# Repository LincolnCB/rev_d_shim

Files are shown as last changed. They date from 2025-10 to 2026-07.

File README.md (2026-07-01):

# Shim Amplifier System, Rev. D



This repo is the source code for the Rev. D version of our shim amplifier system. It is primarily written by me, Lincoln Craven-Brightman, and based on the work of Pavel Demin, who provided a great starting point with his repo for Zynq-7000 development.

To use this repo, you will need the following repos. Each repo has a DOI that can be accessed on its own README.
- Our build environment repo, [Zynq Toolbox](https://github.com/LincolnCB/zynq_toolbox) ([https://github.com/LincolnCB/zynq_toolbox](https://github.com/LincolnCB/zynq_toolbox)), which is an extension of Pavel's original [Red Pitay Notes](https://github.com/pavel-demin/red-pitaya-notes) repo.
- The hardware design files for the Rev. D version of our shim amplifier system, which have been created by Don Straney and are available in our [hardware repo](https://github.com/stockmann-lab/shim_amp_hardware_linear/) ([https://github.com/stockmann-lab/shim_amp_hardware_linear/](https://github.com/stockmann-lab/shim_amp_hardware_linear/))

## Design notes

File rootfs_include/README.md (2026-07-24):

# Rev D Shim Amplifier

This system includes multiple command-line tools for controlling, driving, and diagnosing the shim hardware. These all currently need to be run with sudo privileges in order to handle memory mapping.

| Tool | Type | What it does |
|---|---|---|
| `reset-shims` | One-shot utility | Safely resets the shim hardware to a known idle state — powers off and pulses the command/data buffer resets. Good for recovering between runs without a power cycle. |
| `status` | One-shot, read-only | Reads the FPGA system status register and prints a human-readable snapshot (hardware state, trigger count, clock frequencies, timing debug, per-board FIFO status). Observes only, never drives hardware. |
| `static-shims` | Interactive | Drives the shims with **static (DC)** currents. Set per-channel currents manually, from files, or on triggers. |
| `waveform` | One-shot, file-driven | Plays a multi-channel **waveform** from a CSV on the DACs, optionally reads back ADC samples, and logs trigger times. Configurable clock, lockout, and iteration count. |
| `shim-test` | Interactive | Manual test bench for **every aspect** of the shim driver — exercise the system, clock, DACs, ADCs, trigger, and streaming/experiment features by hand. For bring-up, debugging, and validation. |

## At a glance

- **Diagnostics / recovery:** `status` (inspect the hardware) and `reset-shims` (recover to idle).
- **Driving the hardware:** `static-shims` for DC currents and `waveform` for time-varying playback.
- **Development / debugging:** `shim-test` as the low-level interactive driver test tool.

Use the `-h` or `--help` option with any command to see its usage and available options.

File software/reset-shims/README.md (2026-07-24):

# reset-shims

Small utility that safely resets the Rev D Shim hardware to a known idle state.

On run it:
1. Maps the system control register (`0x40000000`) via `/dev/mem`.
2. Powers the system off (control and power boards disabled).
3. Pulses the 17-bit command and data buffer resets (assert, brief delay, release).

Useful for recovering the buffers/state between runs without a full power cycle.

## Usage

```bash
reset-shims
```

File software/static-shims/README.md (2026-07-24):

# static-shims

Interactive command-line tool for driving the Rev D shim amplifier with **static** (DC) currents. It boots the FPGA hardware, then accepts single-character commands to set per-channel currents manually, from files, or on external/forced triggers.

## Usage

```bash
static-shims [--verbose] <channel_count>
```

- `channel_count` — number of active shim channels (1–64).
- `--verbose` — enable detailed logging.

On start it initializes hardware, configures the clock, and drops into a `static-shims>` prompt. `Ctrl+C` (or `Q`) powers the system off safely before exiting.

## Commands

**General**
| Cmd | Action |
|---|---|
| `H` | Brief help |
| `?` | Extended guide (file format + commands) |
| `Q` | Quit (powers off) |
| `S` | Print system/hardware status |
| `P` | Power amplifier on |
| `X` | Hard reset: power off, unload file, clear buffers |
| `Z` | Zero all currents, unload file, clear buffers |
| `I [file]` | Read currents from ADC (optionally dump to file) |

**Manual**
| Cmd | Action |
|---|---|
| `n x` | Set channel `n` to `x` amperes |
| `U x1 x2...` | Update all channels to given amps |
| `B x1 x2...` | Buffer all channels, wait for trigger |
| `C` | Run calibration |
| `D t` | Set trigger lockout time (ms, default 10.0) |
| `T [n]` | Trigger next shim row `n` times (default 1) |

**File**
| Cmd | Action |
|---|---|
| `L [file]` | Load shim block file (or reload last) |
| `A [data]` | Load inline array as a shim block (`/` = newline) |
| `E` | Exit loaded file, reset trigger counter |
| `R` | Reset buffers, restart loaded file |

## Layout

- `static-shims.c` — entry point / REPL loop and boot sequence.
- `src/`, `include/` — `commands/` (command parsing + execution), `input/` (line parsing), `file_handling/` (shim block files), and `static_hardware/` (`hw_*` hardware control API, wrapping the FPGA `sys`/`clk`/`dac`/`adc`/`trigger` controllers).

Max 64 channels; currents limited to ±5.0 A.

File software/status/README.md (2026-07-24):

# status

Command-line diagnostic tool that reads the Rev D shim amplifier's FPGA system status register (mapped at `0x40100000`) and prints a human-readable snapshot of the hardware state. It is read-only — it only observes and reports, and never drives or reconfigures the hardware.

## Usage

```bash
status
```

No arguments. Run it on the target to dump the current status of the shim hardware.

## What it reports

- **Hardware status** — decoded state (`S_IDLE`…`S_HALTED`), status code (`STS_*`), and the board number associated with the current status.
- **Trigger count** — number of hardware triggers seen.
- **Clock frequencies** — SPI clock and SPI source clock, in Hz.
- **Timing debug register** — clock-locked/SPI-off flags, DAC/ADC `~CS` high times, and the SPI clock snoop reconfiguration state machine state.
- **Minimum delay times** — DAC and ADC "delay too short" thresholds, in SPI clock cycles.
- **Per-board FIFO status (boards 0–7)** — DAC and ADC command/data FIFO status (word count, full / almost-full / empty / almost-empty / present flags), the last received command word, and the command count since reset.
- **Trigger FIFOs** — command and data FIFO status.

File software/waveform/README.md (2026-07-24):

# waveform

Command-line tool that plays a multi-channel waveform on the Rev D shim amplifier's DACs, optionally reads back ADC samples, and logs hardware trigger times. It streams commands to the FPGA over the DAC/ADC/trigger control interfaces and powers the hardware safely on and off around the run.

## Usage

```
waveform <file.csv> [OPTIONS]
```

| Argument / flag | Type | Default | Meaning |
|---|---|---|---|
| `<file.csv>` | path | — (required) | DAC waveform input file |
| `-a`, `--adc <path>` | path | none | ADC read-timestamp file (enables readback) |
| `-l`, `--lockout <float>` | ms | `10.0` | Trigger lockout time in milliseconds |
| `-c`, `--clk_MHz <float>` | MHz | `30.0` | SPI clock frequency |
| `-i`, `--iters <int>` | int | `1` | Number of times to replay the file(s) |
| `-h`, `--help` | — | — | Show usage |

> Note: all timestamps **inside the CSV files are in seconds**. The `--lockout` flag is the one exception and is given in milliseconds.

## Input (DAC) CSV format

One data row per line: the first column is a timestamp in **seconds**, and each remaining column is a channel current in **amps**.

```
# comments start with '#'; blank lines are ignored
# t_sec, ch0_amps, ch1_amps, ...
0.000,   0.0,   0.0
0.001,   0.5,  -0.5
0.002,   1.0,  -1.0
```

- Fields may be separated by commas, spaces, or tabs.
- There is **no text header row** — a header must be commented out (`#`) or it
  will fail to parse as numbers.
- Channel count is `fields - 1` and must be between `1` and `64`. Channels map
  onto 8-channel boards; unused channels on an active board are driven to 0.
- Currents must be within `[-3.0, 3.0]` A or validation fails.
- Timestamps must be non-negative.

### Trigger points

A row is a **trigger point** (the start of a new sweep) if it is the first row, or if its timestamp is *lower* than the previous row's (time has reset). Within a sweep, each row is applied as a delay from the previous row. The smallest gap between consecutive rows in a sweep must be at least the hardware's minimum DAC/ADC delay for the selected clock, or the run is rejected.

## ADC (readback) CSV format

A plain list of read timestamps in **seconds**, one per line, no header and no channel columns:

```
0.0005
0.0015
0.0025
```

The same trigger-point rule applies, and the ADC file's trigger count **must match** the DAC file's trigger count.

## Output files

Written next to the input file:

| File | When | Contents |
|---|---|---|
| `<input>.trig_t_sec.csv` | always | one hardware trigger time (seconds) per line |
| `<input>.adc_out_A.csv` | with `--adc` | active-channel readback amps, one sample per line |

Press `Ctrl+C` to stop early; the hardware is powered off before exit.

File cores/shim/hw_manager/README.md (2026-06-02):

***Updated 2025-09-22***
# Hardware Manager Core

The `hw_manager` module manages the hardware system's startup, operation, and shutdown processes. It implements a state machine to sequence power-up, configuration, SPI subsystem enable, and error/shutdown handling.

## Inputs and Outputs

### Inputs

- **Clock and Reset**
  - `clk`: System clock.
  - `aresetn`: Active-low reset.

- **System Control**
  - `ctrl_en`: Control board enable (turn the system on).
  - `pow_en`: Power stage enable (turn on power stage).
  - `spi_off`: SPI system powered off.
  - `calc_n_cs_done`: DAC/ADC n_cs timing calculation done.
  - `ext_en`: External enable (deadman shutdown).

- **Configuration Status**
  - `lock_viol`: Configuration lock violation.
  - `ctrl_en_oob`: Control board enable register out of bounds.
  - `pow_en_oob`: Power stage enable register out of bounds.
  - `cmd_buf_reset_oob`: Command buffer reset out of bounds.
  - `data_buf_reset_oob`: Data buffer reset out of bounds.
  - `thresh_val_oob`: Threshold average out of bounds.
  - `thresh_window_oob`: Threshold window out of bounds.
  - `thresh_en_oob`: Threshold enable register out of bounds.
  - `boot_test_skip_oob`: Boot test skip out of bounds.
  - `debug_oob`: Debug out of bounds.
  - `dac_cal_init_oob`: DAC calibration initial value out of bounds.

- **Shutdown Sense**
  - `shutdown_sense_sts [7:0]`: Shutdown sense (per board).

- **Threshold Status**
  - `over_thresh [7:0]`: DAC over threshold (per board).
  - `thresh_underflow [7:0]`: DAC threshold core FIFO underflow (per board).
  - `thresh_overflow [7:0]`: DAC threshold core FIFO overflow (per board).

- **Trigger Buffer and Commands**
  - `bad_trig_cmd`: Bad trigger command.
  - `trig_cmd_buf_overflow`: Trigger command buffer overflow.
  - `trig_data_buf_underflow`: Trigger data buffer underflow.
  - `trig_data_buf_overflow`: Trigger data buffer overflow.

- **DAC Buffers and Commands**
  - `dac_boot_fail [7:0]`: DAC boot failure (per board).
  - `bad_dac_cmd [7:0]`: Bad DAC command (per board).
  - `dac_cal_oob [7:0]`: DAC calibration out of bounds (per board).
  - `dac_val_oob [7:0]`: DAC value out of bounds (per board).
  - `dac_cmd_buf_underflow [7:0]`: DAC command buffer underflow (per board).
  - `dac_cmd_buf_overflow [7:0]`: DAC command buffer overflow (per board).
  - `dac_data_buf_underflow [7:0]`: DAC data buffer underflow (per board).
  - `dac_data_buf_overflow [7:0]`: DAC data buffer overflow (per board).
  - `unexp_dac_trig [7:0]`: Unexpected DAC trigger (per board).
  - `ldac_misalign [7:0]`: LDAC misalignment (per board).
  - `dac_delay_too_short [7:0]`: DAC delay too short (per board).

- **ADC Buffers and Commands**
  - `adc_boot_fail [7:0]`: ADC boot failure (per board).
  - `bad_adc_cmd [7:0]`: Bad ADC command (per board).
  - `adc_cmd_buf_underflow [7:0]`: ADC command buffer underflow (per board).
  - `adc_cmd_buf_overflow [7:0]`: ADC command buffer overflow (per board).
  - `adc_data_buf_underflow [7:0]`: ADC data buffer underflow (per board).
  - `adc_data_buf_overflow [7:0]`: ADC data buffer overflow (per board).
  - `unexp_adc_trig [7:0]`: Unexpected ADC trigger (per board).
  - `adc_delay_too_short [7:0]`: ADC delay too short (per board).

### Outputs

- **System Control**
  - `unlock_cfg`: Lock configuration.
  - `spi_clk_gate`: SPI clock gate.
  - `spi_en`: SPI subsystem enable.
  - `spi_halt`: SPI subsystem halt (halt SPI subsystem without resetting it).
  - `shutdown_sense_en`: Shutdown sense enable.
  - `block_bufs`: Block command/data buffers (active high).
  - `n_shutdown_force`: Shutdown force (negated).
  - `shutdown_rst`: Shutdown reset.

- **Status and Interrupts**
  - `status_word [31:0]`: Status word containing board number, status code, and state.
  - `ps_interrupt`: Interrupt signal.

## Operation

### State Machine Overview

The state machine states are encoded as follows:
- `4'd1`: `S_IDLE` - Waits for `ctrl_en` to go high. Checks out-of-bounds configuration values (`ctrl_en_oob`, `pow_en_oob`, `cmd_buf_reset_oob`, `data_buf_reset_oob`, `thresh_val_oob`, `thresh_window_oob`, `thresh_en_oob`, `boot_test_skip_oob`, `debug_oob`, `dac_cal_init_oob`). If any OOB condition is detected, transitions to `S_HALTING` with the corresponding status code. If checks pass, locks configuration and transitions to SPI reset confirmation.
- `4'd2`: `S_CONFIRM_SPI_RST` - Makes sure the SPI system is powered off (`spi_off`). If not powered off within `SPI_RESET_WAIT`, transitions to `S_HALTING` with a timeout status.
- `4'd3`: `S_POWER_ON_CRTL_BRD` - Releases shutdown force (`n_shutdown_force` high) and waits for `SHUTDOWN_FORCE_DELAY`.
- `4'd4`: `S_CONFIRM_SPI_START` - Enables SPI clock/subsystem and waits for the SPI subsystem to start (`spi_off` deasserted). If startup times out, or DAC/ADC boot failures are observed, transitions to `S_HALTING` with the appropriate status code.
- `4'd5`: `S_WAIT_FOR_POW_EN` - Waits for `pow_en` before powering on amplifier boards.
- `4'd6`: `S_POWER_ON_AMP_BRD` - Pulses `shutdown_rst` high for `SHUTDOWN_RESET_PULSE`.
- `4'd7`: `S_AMP_POWER_WAIT` - Waits for `SHUTDOWN_RESET_DELAY`, then enables shutdown sense, unblocks buffers, and asserts `ps_interrupt`.
- `4'd8`: `S_RUNNING` - Normal operation. Continuously monitors for halt conditions. If any error or shutdown condition occurs, transitions to `S_HALTING`.
- `4'd9`: `S_HALTING` - One-cycle transition that drives outputs to the halted state and asserts `ps_interrupt`.
- `4'd10`: `S_HALTED` - Halted state. All outputs are disabled, and the system waits for both `ctrl_en` and `pow_en` to go low.

### Halt/Error Conditions

The system transitions through `S_HALTING` to `S_HALTED` and sets the appropriate status code if any of the following occur:
- `ctrl_en` or `pow_en` goes low (processing system shutdown)
- Configuration lock violation (`lock_viol`)
- Out-of-bounds configuration values (`ctrl_en_oob`, `pow_en_oob`, `cmd_buf_reset_oob`, `data_buf_reset_oob`, `thresh_val_oob`, `thresh_window_oob`, `thresh_en_oob`, `boot_test_skip_oob`, `debug_oob`, `dac_cal_init_oob`)
- Shutdown detected via `shutdown_sense_sts` or `ext_en` deassertion
- Thresholds exceeded or hardware error underflow/overflow conditions
- Trigger buffer or command errors
- DAC/ADC boot failure, buffer or command errors (per board)
- Unexpected DAC/ADC triggers occur
- SPI subsystem fails to start or initialize within timeout

### Status Word Format

The 32-bit `status_word` is formatted as:
```
[31:29] - Board number (3 bits)
[28:4]  - Status code (25 bits)
[3:0]   - State machine state (4 bits)
```

### Status Codes

Status codes are 25 bits wide and include:

- `25'h0001`: `STS_OK` - System is operating normally.
- `25'h0002`: `STS_PS_SHUTDOWN` - Processing system shutdown.
- `25'h0100`: `STS_SPI_RESET_TIMEOUT` - SPI initialization timeout.
- `25'h0101`: `STS_SPI_START_TIMEOUT` - SPI start timeout.
- `25'h0200`: `STS_LOCK_VIOL` - Configuration lock violation.
- `25'h0201`: `STS_CTRL_EN_OOB` - Control board enable register out of bounds.
- `25'h0202`: `STS_POW_EN_OOB` - Power stage enable register out of bounds.
- `25'h0203`: `STS_CMD_BUF_RESET_OOB` - Command buffer reset out of bounds.
- `25'h0204`: `STS_DATA_BUF_RESET_OOB` - Data buffer reset out of bounds.
- `25'h0205`: `STS_THRESH_VAL_OOB` - Threshold average out of bounds.
- `25'h0206`: `STS_THRESH_WINDOW_OOB` - Threshold window out of bounds.
- `25'h0207`: `STS_THRESH_EN_OOB` - Threshold enable register out of bounds.
- `25'h0208`: `STS_BOOT_TEST_SKIP_OOB` - Boot test skip out of bounds.
- `25'h0209`: `STS_DEBUG_OOB` - Debug out of bounds.
- `25'h020A`: `STS_DAC_CAL_INIT_OOB` - DAC calibration initial value out of bounds.
- `25'h0300`: `STS_SHUTDOWN_SENSE` - Shutdown sense detected.
- `25'h0301`: `STS_EXT_SHUTDOWN` - External shutdown triggered.
- `25'h0400`: `STS_OVER_THRESH` - DAC over threshold.
- `25'h0401`: `STS_THRESH_UNDERFLOW` - DAC threshold FIFO underflow.
- `25'h0402`: `STS_THRESH_OVERFLOW` - DAC threshold FIFO overflow.
- `25'h0500`: `STS_BAD_TRIG_CMD` - Bad trigger command.
- `25'h0501`: `STS_TRIG_CMD_BUF_OVERFLOW` - Trigger command buffer overflow.
- `25'h0502`: `STS_TRIG_DATA_BUF_UNDERFLOW` - Trigger data buffer underflow.
- `25'h0503`: `STS_TRIG_DATA_BUF_OVERFLOW` - Trigger data buffer overflow.
- `25'h0600`: `STS_DAC_BOOT_FAIL` - DAC boot failure.
- `25'h0601`: `STS_BAD_DAC_CMD` - Bad DAC command.
- `25'h0602`: `STS_DAC_CAL_OOB` - DAC calibration out of bounds.
- `25'h0603`: `STS_DAC_VAL_OOB` - DAC value out of bounds.
- `25'h0604`: `STS_DAC_CMD_BUF_UNDERFLOW` - DAC command buffer underflow.
- `25'h0605`: `STS_DAC_CMD_BUF_OVERFLOW` - DAC command buffer overflow.
- `25'h0606`: `STS_DAC_DATA_BUF_UNDERFLOW` - DAC data buffer underflow.
- `25'h0607`: `STS_DAC_DATA_BUF_OVERFLOW` - DAC data buffer overflow.
- `25'h0608`: `STS_UNEXP_DAC_TRIG` - Unexpected DAC trigger.
- `25'h0609`: `STS_LDAC_MISALIGN` - LDAC misalignment.
- `25'h060A`: `STS_DAC_DELAY_TOO_SHORT` - DAC delay too short.
- `25'h0700`: `STS_ADC_BOOT_FAIL` - ADC boot failure.
- `25'h0701`: `STS_BAD_ADC_CMD` - Bad ADC command.
- `25'h0702`: `STS_ADC_CMD_BUF_UNDERFLOW` - ADC command buffer underflow.
- `25'h0703`: `STS_ADC_CMD_BUF_OVERFLOW` - ADC command buffer overflow.
- `25'h0704`: `STS_ADC_DATA_BUF_UNDERFLOW` - ADC data buffer underflow.
- `25'h0705`: `STS_ADC_DATA_BUF_OVERFLOW` - ADC data buffer overflow.
- `25'h0706`: `STS_UNEXP_ADC_TRIG` - Unexpected ADC trigger.
- `25'h0707`: `STS_ADC_DELAY_TOO_SHORT` - ADC delay too short.

## Board Number Extraction

For error/status signals that are 8 bits wide (per board), the board number is extracted as the index of the first asserted bit (0–7).

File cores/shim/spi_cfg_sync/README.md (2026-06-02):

***Updated 2025-09-22***
# SPI Configuration Synchronization Core

The `spi_cfg_sync` module synchronizes configuration signals from the AXI clock domain to the SPI clock domain.

## Inputs and Outputs

### Inputs

- **Clocks and Reset**
  - `aclk`: AXI domain clock signal.
  - `aresetn`: Active-low reset for AXI domain.
  - `spi_clk`: SPI domain clock signal.
  - `sync_resetn`: Active-low reset for SPI domain synchronization.

- **AXI Domain Configuration Inputs**
  - `thresh_val [14:0]`: Threshold average configuration.
  - `thresh_window [31:0]`: Threshold window configuration.
  - `thresh_en`: Threshold enable signal.
  - `spi_en`: SPI enable signal
  - `block_bufs`: Block buffers enable signal.
  - `dac_n_cs_high_time [4:0]`: DAC chip select high time configuration.
  - `adc_n_cs_high_time [7:0]`: ADC chip select high time configuration.
  - `boot_test_skip [15:0]`: Boot test skip mask (per-core).
  - `debug [15:0]`: Debug mask (per-core).
  - `dac_cal_init [15:0]`: DAC calibration initialization value (signed).

### Outputs

- **SPI Domain Synchronized Outputs**
  - `thresh_val_sync [14:0]`: Synchronized threshold average.
  - `thresh_window_sync [31:0]`: Synchronized threshold window.
  - `thresh_en_sync`: Synchronized threshold enable.
  - `spi_en_sync`: Synchronized SPI enable.
  - `block_bufs_sync`: Synchronized block buffers enable.
  - `dac_n_cs_high_time_sync [4:0]`: Synchronized DAC chip select high time.
  - `adc_n_cs_high_time_sync [7:0]`: Synchronized ADC chip select high time.
  - `boot_test_skip_sync [15:0]`: Synchronized boot test skip mask.
  - `debug_sync [15:0]`: Synchronized debug mask.
  - `dac_cal_init_sync [15:0]`: Synchronized DAC calibration initialization value (signed).

## Operation

- Each AXI domain input is synchronized to the SPI clock domain using either `sync_coherent` or `sync_incoherent` modules.
- **Coherent synchronization** is used for multi-bit data that must be coherent across bits.
- **Incoherent synchronization** is used for data where individual bits are not coherent with each other.
- Default values are provided for each output in case of reset:
  - `thresh_val_sync`: 0x1000
  - `thresh_window_sync`: 0x00010000
  - `thresh_en_sync`: 0
  - `spi_en_sync`: 0
  - `block_bufs_sync`: 1
  - `dac_n_cs_high_time_sync`: 31 (capped max)
  - `adc_n_cs_high_time_sync`: 255 (capped max)
  - `boot_test_skip_sync`: 0
  - `debug_sync`: 0
  - `dac_cal_init_sync`: 0

## Notes

- The `sync_coherent` module is used for timing-critical multi-bit configuration signals that need coherency across bits.
- The `sync_incoherent` module is used for control signals and masks where bit coherency is not required.
- The `spi_en` signal uses a deeper synchronizer (4 stages) to provide extra delay for this signal.
- For more details, refer to the Verilog source code.

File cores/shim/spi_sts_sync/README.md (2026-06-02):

***Updated 2024-08-01***
# SPI System Status Synchronization Core

The `spi_sts_sync` module synchronizes a variety of status signals from the SPI clock domain into the AXI (PS) clock domain.

## Inputs and Outputs

### Inputs

- **Clocks and Reset**
  - `aclk`: AXI (PS) clock signal.
  - `aresetn`: Active-low reset signal for the AXI domain.
  - `spi_clk`: SPI domain clock signal.
  - `sync_resetn`: Active-low reset signal for the SPI domain synchronization.

- **SPI Domain Status Inputs**
  - `spi_off`: Indicates the SPI subsystem is powered off.
  - `over_thresh [7:0]`: Threshold core over-threshold status.
  - `thresh_underflow [7:0]`: Threshold core threshold underflow status.
  - `thresh_overflow [7:0]`: Threshold core threshold overflow status.
  - `bad_trig_cmd`: Bad trigger command detected.
  - `trig_data_buf_overflow`: Trigger data buffer overflow.
  - `dac_boot_fail [7:0]`: DAC boot failure status.
  - `bad_dac_cmd [7:0]`: Bad DAC command detected.
  - `dac_cal_oob [7:0]`: DAC calibration out-of-bounds.
  - `dac_val_oob [7:0]`: DAC value out-of-bounds.
  - `dac_cmd_buf_underflow [7:0]`: DAC command buffer underflow.
  - `dac_data_buf_overflow [7:0]`: DAC data buffer overflow.
  - `unexp_dac_trig [7:0]`: Unexpected DAC trigger.
  - `adc_boot_fail [7:0]`: ADC boot failure status.
  - `bad_adc_cmd [7:0]`: Bad ADC command detected.
  - `adc_cmd_buf_underflow [7:0]`: ADC command buffer underflow.
  - `adc_data_buf_overflow [7:0]`: ADC data buffer overflow.
  - `unexp_adc_trig [7:0]`: Unexpected ADC trigger.

### Outputs

- **AXI Domain Synchronized Outputs**
  - `spi_off_sync`: Synchronized SPI off status.
  - `over_thresh_sync [7:0]`: Synchronized threshold core over-threshold status.
  - `thresh_underflow_sync [7:0]`: Synchronized threshold core threshold underflow status.
  - `thresh_overflow_sync [7:0]`: Synchronized threshold core threshold overflow status.
  - `bad_trig_cmd_sync`: Synchronized bad trigger command status.
  - `trig_data_buf_overflow_sync`: Synchronized trigger data buffer overflow status.
  - `dac_boot_fail_sync [7:0]`: Synchronized DAC boot failure status.
  - `bad_dac_cmd_sync [7:0]`: Synchronized bad DAC command status.
  - `dac_cal_oob_sync [7:0]`: Synchronized DAC calibration out-of-bounds status.
  - `dac_val_oob_sync [7:0]`: Synchronized DAC value out-of-bounds status.
  - `dac_cmd_buf_underflow_sync [7:0]`: Synchronized DAC command buffer underflow status.
  - `dac_data_buf_overflow_sync [7:0]`: Synchronized DAC data buffer overflow status.
  - `unexp_dac_trig_sync [7:0]`: Synchronized unexpected DAC trigger status.
  - `adc_boot_fail_sync [7:0]`: Synchronized ADC boot failure status.
  - `bad_adc_cmd_sync [7:0]`: Synchronized bad ADC command status.
  - `adc_cmd_buf_underflow_sync [7:0]`: Synchronized ADC command buffer underflow status.
  - `adc_data_buf_overflow_sync [7:0]`: Synchronized ADC data buffer overflow status.
  - `unexp_adc_trig_sync [7:0]`: Synchronized unexpected ADC trigger status.

## Operation

- Each input signal from the SPI domain is synchronized to the AXI clock domain using the `sync_coherent` module.
- On AXI domain reset (`aresetn` low), all synchronized output signals are set to their default values (zeros).

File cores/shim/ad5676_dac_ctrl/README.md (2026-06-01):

**Updated 2026-05-29**
# AD5676 DAC Control Core

The `ad5676_dac_ctrl` module implements command-driven control for the Analog Devices AD5676 DAC in the Rev D shim firmware. It manages the boot-time register test, SPI transactions, command sequencing, per-channel calibration, error detection, and synchronization for all 8 DAC channels.

## Supported Device

- AD5676 (16-bit, 8-channel DAC)

## Inputs and Outputs

### Inputs

- `clk`, `resetn`: Main clock and active-low reset.
- `boot_test_skip`: Skips boot-time SPI register test if asserted.
- `debug`: Enables debug mode (debug outputs to the data buffer).
- `n_cs_high_time [4:0]`: Chip select high time in clock cycles (max 31), latched when exiting reset.
- `cal_init_val [15:0]`: Default signed calibration value for all channels on reset (in 2's complement).
- `cmd_buf_word [31:0]`: Command word from buffer.
- `cmd_buf_empty`: Indicates command buffer is empty.
- `trigger`: External trigger signal.
- `ldac_shared`: Shared LDAC signal (for error detection).
- `miso_sck`, `miso_resetn`, `miso`: SPI MISO clock, reset, and data.
- `data_buf_full`: Indicates data buffer is full.

### Outputs

- `setup_done`: Indicates successful boot/setup after the boot sequence or skipped midrange initialization completes.
- `cmd_buf_rd_en`: Enables reading the next command word.
- `waiting_for_trig`: Indicates waiting for trigger.
- `data_buf_wr_en`: Enables writing a data word to the output buffer.
- `data_word [31:0]`: Packed debug or readback data.
- `last_received_cmd [31:0]`: Most recently accepted command word.
- `cmds_since_reset [31:0]`: Saturating count of commands accepted since reset.
- Error flags: `boot_fail`, `cmd_buf_underflow`, `data_buf_overflow`, `unexp_trig`, `ldac_misalign`, `delay_too_short`, `bad_cmd`, `cal_oob`, `dac_val_oob`.
- `abs_dac_val_concat [119:0]`: Concatenated absolute DAC values (8 × 15 bits).
- `n_cs`: SPI chip select (active low).
- `mosi`: SPI MOSI data.
- `ldac`: LDAC output for DAC update.

## State Machine

The state machine in `ad5676_dac_ctrl` uses the following codes:

| State Code | Name | Description |
|:---:|:---|:---|
| `0` | `S_RESET` | Reset state; waits for `resetn` deassertion. |
| `1` | `S_INIT` | Initialization; starts SPI register write for boot test. |
| `2` | `S_TEST_WR`  | Boot test: writes test value to DAC register. |
| `3` | `S_REQ_RD` | Boot test: requests readback of test value. |
| `4` | `S_TEST_RD`  | Boot test: reads back register value and checks for match. |
| `5` | `S_SET_MID`  | Boot test: sets all DAC channels to midrange value after successful test. |
| `6` | `S_IDLE` | Idle; waits for new command from buffer. |
| `7` | `S_DELAY` | Delay timer; waits for specified cycles before next command. |
| `8` | `S_TRIG_WAIT`| Waits for external trigger signal. |
| `9` | `S_DAC_WR` | Performs DAC write sequence for all channels. |
| `10` | `S_DAC_WR_CH`| Immediately and simply write to a single DAC channel. |
| `15` | `S_ERROR` | Error state; indicates boot/readback failure or invalid command/condition.  |

State transitions are managed based on command type, trigger, delay, and error conditions.

### Boot Test

If `boot_test_skip` is asserted, boot-time SPI register test is skipped, but the core still runs the midrange initialization sequence before asserting `setup_done`.

Otherwise, the core performs a boot test by writing a known value to a DAC channel and reading it back to verify correct operation. If the readback does not match the expected value, the core transitions to `S_ERROR`.

The boot test sequence is as follows:
1. `S_RESET -> S_INIT`: After exiting reset, the core prepares to write a test value to DAC channel 5.

2. `S_INIT -> S_TEST_WR`: Writes the test value (`DAC_TEST_VAL`) to channel 5.
  - SPI command composition:
    - `[23:20]` = `0001` (SPI register write command)
    - `[19]`    = `0` (reserved)
    - `[18:16]` = `101` (channel 5)
    - `[15:0]`  = `DAC_TEST_VAL` (`1000000000001010`, `0x800A`)
  - SPI word written:
    ```
    0001_0_101_1000000000001010
    0x15800A
    ```

3. `S_TEST_WR -> S_REQ_RD`: After write completion, requests readback of channel 5.
  - SPI command composition:
    - `[23:20]` = `1001` (SPI register read command)
    - `[19]`    = `0` (reserved)
    - `[18:16]` = `101` (channel 5)
    - `[15:0]`  = `0000000000000000`, `0x0000`
  - SPI word written:
    ```
    1001_0_101_0000000000000000
    0x950000
    ```

4. `S_REQ_RD -> S_TEST_RD`: After read request completion, reads back the register value while also resetting it.
  - SPI command composition:
    - `[23:20]` = `0001` (SPI register write command)
    - `[19]`    = `0` (reserved)
    - `[18:16]` = `101` (channel 5)
    - `[15:0]`  = `DAC_MIDRANGE` (`1000000000000000`, `0x8000`)
  - SPI word written:
    ```
    0001_0_101_1000000000000000
    0x158000
    ```
  - SPI response composition:
    - `[23:16]` = Undefined (not used)
    - `[15:0]` = Readback value (should match `DAC_TEST_VAL`)
  - SPI response expected (MISO):
    ```
    XXXXXXX_1000000000001010
    0xXX800A
    ```

5. `S_TEST_RD -> S_SET_MID`: If readback matches expected value, write midrange value to all DAC channels; otherwise, transitions to `S_ERROR` and sets `boot_fail`.

6. `S_SET_MID -> S_IDLE`: After all channels are set to midrange, setup is complete and `setup_done` is asserted.

When `boot_test_skip` is asserted, the core transitions from `S_RESET` directly to `S_SET_MID` and performs only step 6.

## Operation

The core operates based on 32-bit word commands read from the command buffer. These are read sequentially, and the core executes each command fully before reading the next (excepting the CANCEL command).

### Command Types

- **NO_OP (`3'd0`):** Delay or trigger wait, optional LDAC pulse.
- **SET_CAL (`3'd1`):** Set calibration value for a channel.
- **DAC_WR (`3'd2`):** Write DAC values (4 words, 2 channels each).
- **DAC_WR_CH (`3'd3`):** Write single DAC channel.
- **GET_CAL (`3'd4`):** Read calibration value for a channel.
- **ZERO (`3'd5`):** Set all DAC channels to calibrated midrange (zero) values.
- **CANCEL (`3'd7`):** Cancel current wait or delay.

### Command Word Structure

- `[31:29]` — **Command Code** (3 bits).

#### NO_OP (`3'd0`)
- `[28]` — **TRIGGER WAIT**: If set, waits for external trigger (`trigger` input); otherwise, uses value as delay timer.
- `[27]` — **CONTINUE**: If set, expects next command immediately after current completes; if not, returns to IDLE unless buffer underflow.
- `[26]` — **LDAC**: If set, pulses `ldac` output at end of command.
- `[24:0]` — **Value**: If TRIGGER WAIT is set, this is the trigger counter (number of triggers to wait for); otherwise, it is the delay timer (number of clock cycles to wait, zero is allowed).

This command does not update DAC values, but can pulse LDAC if requested. If TRIGGER WAIT is set, the core waits for the specified number of external trigger events. Otherwise, it waits for the delay timer to expire.

Note that the trigger counter represents the exact number of triggers to wait for, so a value of 0 means finish immediately (no triggers), and a value of 1 means wait for one trigger.

**State transitions:**
- `S_IDLE -> S_TRIG_WAIT/S_DELAY -> S_IDLE/S_ERROR/next_cmd_state`
- Transition to the next command state if one is present. Otherwise, go to `S_ERROR` if CONTINUE is set, or return to `S_IDLE` if not.

#### SET_CAL (`3'd1`)
- `[18:16]` — **Channel Index** (0–7)
- `[15:0]`  — **Signed Calibration Value** (range: -`ABS_CAL_MAX` to `ABS_CAL_MAX`)

Sets per-channel signed calibration value. Calibration is applied to DAC updates before conversion to offset format. Out-of-bounds calibration sets the `cal_oob` error flag.

**State transitions:**
- `S_IDLE -> S_IDLE/S_ERROR/next_cmd_state`
- Will set `cal_oob` if the calibration value is out of bounds.
- Transition to the next command state if one is present. Otherwise, return to `S_IDLE`.

#### DAC_WR (`3'd2`)
- `[28]` — **TRIGGER WAIT**
- `[27]` — **CONTINUE**
- `[26]` — **LDAC**
- `[24:0]` — **Value**: If TRIGGER WAIT is set, this is the trigger counter (number of triggers to wait for) after the DAC update; otherwise, it is the minimum delay before the DAC write sequence may begin. When `do_pre_delay` is asserted and the value is above the latched minimum delay, the core waits in `S_PRE_DELAY` before starting the SPI writes.

Initiates an 8-channel DAC update sequence. The core expects 4 subsequent words, each containing two 16-bit DAC values (SIGNED 16 bit integers): `[31:16]` for channel N+1, `[15:0]` for channel N. Channels are updated in pairs: (0,1), (2,3), (4,5), (6,7). If `do_pre_delay` is enabled and the programmed delay is greater than the latched minimum delay, the core waits before beginning the SPI transaction; otherwise it starts immediately. If TRIGGER WAIT is set, the trigger wait happens after the write completes.

If TRIGGER WAIT is set, the core waits for the specified number of triggers after the write completes. The trigger counter represents the exact number of triggers to wait for, so a value of 0 means finish immediately (no triggers), and a value of 1 means wait for one trigger.

**State transitions:**
- `S_IDLE -> S_PRE_DELAY/S_DAC_WR -> S_TRIG_WAIT/S_IDLE/next_cmd_state`
- Transition to the next command state if one is present. Otherwise, go to `S_ERROR` if CONTINUE is set, or return to `S_IDLE` if not.

#### DAC_WR_CH (`3'd3`)
- `[18:16]` — **Channel Index** (0–7)
- `[15:0]` — **DAC Value**

Writes a single DAC channel with the specified value (SIGNED 16-bit integer). It completes immediately, does not wait for triggers or delays, and does not pulse LDAC automatically.

**State transitions:**
- `S_IDLE -> S_DAC_WR_CH -> S_IDLE/next_cmd_state`
- Transition to the next command state if one is present. Otherwise return to `S_IDLE`.

#### GET_CAL (`3'd4`)
- `[18:16]` — **Channel Index** (0–7)

Reads the current calibration value for the specified channel. Outputs the calibration value to the data buffer with the `CAL_DATA` debug code (see Data Buffer Output section).

**State transitions:**
- `S_IDLE -> S_IDLE/next_cmd_state`
- Transition to the next command state if one is present. Otherwise return to `S_IDLE`.

#### ZERO (`3'd5`)
Sets all DAC channels to their calibrated midrange (zero) values. This command uses the per-channel calibration values to compute the appropriate offset values for each channel and writes them all sequentially. It completes without trigger or delay waits and does not pulse LDAC automatically.

This command is functionally equivalent to the `S_SET_MID` state used during boot initialization.

**State transitions:**
- `S_IDLE -> S_SET_MID -> S_IDLE/next_cmd_state`
- Transition to the next command state if one is present. Otherwise return to `S_IDLE`.

#### CANCEL (`3'd7`)
Cancels current wait or delay if issued while the core is in DELAY or TRIG_WAIT state (or just finishing DAC_WR, about to transition to one of those). This is the only command that can be read without the previous command being finished. After canceling, the core returns to IDLE.

**State transitions:**
- `S_TRIG_WAIT/S_DELAY/S_DAC_WR -> S_IDLE`

## Data Buffer Output

### Debug Mode

If `debug` is asserted, the core outputs debug information in addition to calibration readback. On a given clock cycle, the core will choose what to output in the following priority order:
1. If a calibration read request occurs (`GET_CAL`), output a word using Data Code 8 (`CAL_DATA`), including the channel index and calibration value.
2. If a MISO data word is read during boot test, output a word using Debug Code 1 (`DBG_MISO_DATA`), including the MISO data.
3. If a state transition occurs, output a word using Debug Code 2 (`DBG_STATE_TRANSITION`), including the previous and current state.
4. If the chip select timer starts, output a word using Debug Code 3 (`DBG_N_CS_TIMER`), including the timer value.
5. If the SPI bit counter changes from 0 to nonzero, output a word using Debug Code 4 (`DBG_SPI_BIT`), including the SPI bit value.
6. If a DAC SPI word is about to be issued, output a word using Debug Code 5 (`DBG_DAC_WRITE`), including the 24-bit SPI command.

Debug output format:
- `[31:28]` - Data/Debug Code (see below)
- Remaining bits: data (varies by code, see below)

| Data/Debug Code | Name | Data Format |
|:---:|:---|:---|
| 1 | `DBG_MISO_DATA` | `[15:0]` MISO data |
| 2 | `DBG_STATE_TRANSITION` | `[7:4]` prev_state, `[3:0]` state |
| 3 | `DBG_N_CS_TIMER` | `[7:0]` n_cs_timer value |
| 4 | `DBG_SPI_BIT` | `[4:0]` spi_bit value |
| 5 | `DBG_DAC_WRITE` | `[23:0]` upcoming SPI command |
| 8 | `CAL_DATA` | `[18:16]` channel, `[15:0]` calibration val |

If none of the above conditions are met, the output word is zero and no debug information is written to the data buffer.

**Note:** Calibration data (code 8) is output for `GET_CAL` commands regardless of debug mode setting.

## Calibration

- Per-channel signed calibration, bounded by `ABS_CAL_MAX` (default 4096).
- Calibration values are applied to DAC updates before conversion to offset format.
- Out-of-bounds calibration or DAC values set error flags (`cal_oob`, `dac_val_oob`).
- Absolute DAC values for all channels are concatenated in `abs_dac_val_concat`.

## Error Handling

- Boot readback mismatch (`boot_fail`)
- Unexpected trigger or LDAC assertion (`unexp_trig`)
- Invalid commands (`bad_cmd`)
- Buffer underflow (expect next command with command buffer empty) (`cmd_buf_underflow`)
- Buffer overflow (try to write to data buffer with data buffer full) (`data_buf_overflow`)
- LDAC misalignment error (`ldac_misalign`)
- Delay too short error (`delay_too_short`) - raised when delay timer expires before DAC write sequence completes
- Out-of-bounds calibration or DAC values (`cal_oob`, `dac_val_oob`)

## Notes

- SPI timing and chip select are managed to meet AD5676 requirements.
- The `n_cs_high_time` input is latched when the state machine is in `S_RESET` and clamped to a minimum of 3 cycles to ensure stable timing parameters throughout operation.
- The `min_delay_time` input is latched when the state machine is in `S_RESET` and clamped to a minimum of 216 cycles.
- Offset/signed conversions handled internally (see source for conversion functions).
  - **Offset format**: 0x0000 to 0xFFFF (0 to 65535)
  - **Signed format**: -32768 to +32767
  - **Zero point**: 0x8000 in offset format corresponds to 0 in signed format
- Asynchronous FIFO and synchronizer modules are used for safe cross-domain data transfer.
- Data buffer output is for debug and boot test readback; normal DAC operation does not output samples.

## References

- [AD5676 Datasheet](https://www.analog.com/en/products/ad5676.html)
- [7 Series Memory Resources](https://docs.amd.com/v/u/en-US/ug473_7Series_Memory_Resources)
- See also: [ADS816x ADC Control Core](../ads816x_adc_ctrl/README.md) for similar command-driven architecture.

---
*See the source code for detailed implementation and signal descriptions.*

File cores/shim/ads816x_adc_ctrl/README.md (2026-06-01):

**Updated 2026-05-29**
# ADS816x ADC Control Core

The `ads816x_adc_ctrl` module implements command-driven control for the Texas Instruments ADS816x ADC family (ADS8168, ADS8167, ADS8166) in the Rev D shim firmware. It handles the boot-time On-The-Fly register test, SPI transactions, command sequencing, sample ordering, error detection, synchronization for up to 8 ADC channels.

## Supported Devices

- ADS8168 (`ADS_MODEL_ID = 8`)
- ADS8167 (`ADS_MODEL_ID = 7`)
- ADS8166 (`ADS_MODEL_ID = 6`)

Set the target device using the `ADS_MODEL_ID` parameter.

## Inputs and Outputs

### Inputs

- `clk`, `resetn`: Main clock and active-low reset.
- `boot_test_skip`: Skips the boot-time readback step if asserted.
- `debug`: Enables debug mode (debug outputs to the data buffer).
- `n_cs_high_time [7:0]`: Chip select high time in clock cycles (max 255), latched when exiting reset.
- `cmd_word [31:0]`: Command word from buffer.
- `cmd_buf_empty`: Indicates command buffer is empty.
- `trigger`: External trigger signal.
- `miso_sck`, `miso_resetn`, `miso`: SPI MISO clock, reset, and data.
- `data_buf_full`: Indicates data buffer is full.

### Outputs

- `setup_done`: Indicates successful boot/setup after the boot sequence or skipped readback completes.
- `cmd_buf_rd_en`: Enables reading the next command word.
- `waiting_for_trig`: Indicates waiting for trigger.
- `data_buf_wr_en`: Enables writing a data word to the output buffer.
- `data_word [31:0]`: Packed ADC data (two samples per word).
- `last_received_cmd [31:0]`: Most recently accepted command word.
- `cmds_since_reset [31:0]`: Saturating count of commands accepted since reset.
- Error flags: `boot_fail`, `cmd_buf_underflow`, `data_buf_overflow`, `unexp_trig`, `delay_too_short`, `bad_cmd`.
- `n_cs`: SPI chip select (active low).
- `mosi`: SPI MOSI data.

## State Machine

The state machine in `ads816x_adc_ctrl` uses the following codes:

| State Code | Name | Description |
|:---:|:---|:---|
| `0` | `S_RESET` | Reset state; waits for `resetn` deassertion. |
| `1` | `S_INIT` | Initialization; starts SPI register write for boot test. |
| `2` | `S_SET_OTF`  | Necessary initialization: writes On-The-Fly mode to ADC |
| `3` | `S_REQ_RD` | Boot test: requests readback of On-The-Fly register. |
| `4` | `S_TEST_RD`  | Boot test: reads back register value and checks for match. |
| `5` | `S_IDLE` | Idle; waits for new command from buffer. |
| `6` | `S_DELAY` | Delay timer; waits for specified cycles before next command. |
| `7` | `S_TRIG_WAIT`| Waits for external trigger signal. |
| `8` | `S_ADC_RD` | Performs ADC read sequence for all channels. |
| `9` | `S_ADC_RD_CH`| Immediately and simply read a single ADC channel. |
| `15` | `S_ERROR` | Error state; indicates boot/readback failure or invalid command/condition.  |

State transitions are managed based on command type, trigger, delay, and error conditions.

### Boot Test

If `boot_test_skip` is asserted, the core still performs the On-The-Fly register write during boot, but it skips the readback step. `setup_done` is asserted after the register write completes, and the core transitions from `S_SET_OTF` to `S_IDLE`.

Otherwise, the core performs a boot test by writing to the On-The-Fly mode register and reading it back to verify correct operation. If the readback does not match the expected value, the core transitions to `S_ERROR`.

The boot test sequence is as follows:

1. **`S_RESET -> S_INIT`**: After exiting reset, the core prepares to write the On-The-Fly mode register.

2. **`S_INIT -> S_SET_OTF`**: Writes the On-The-Fly mode command to the ADC.
  - SPI command composition:
    - `[23:19]` = `00001` (SPI register write command)
    - `[18:8]`  = `00000101010` (address for On-The-Fly mode register, `0x2A`)
    - `[7:0]`   = `00000001` (data to set On-The-Fly mode)
  - SPI word written:
    ```
    00001_00000101010_00000001
    0x082A01
    ```

3. **`S_SET_OTF -> S_REQ_RD`**: After write completion, requests readback of the On-The-Fly mode register.
  - SPI command composition:
    - `[23:19]` = `00010` (SPI register read command)
    - `[18:8]`  = `00000101010` (address for On-The-Fly mode register, `0x2A`)
    - `[7:0]`   = `00000000` (data field, unused for read)
  - SPI word written:
    ```
    00010_00000101010_00000000
    0x102A00
    ```

4. **`S_REQ_RD -> S_TEST_RD`**: After read request completion, reads back the register value by writing a 16-bit dummy command to clock out the read data.
  - SPI command composition:
    - `[15:0]` = `0000000000000000` (dummy command; all zeros)
  - SPI word written:
    ```
    0000000000000000
    0x0000
    ```
  - SPI response composition:
    - `[15:8]` = `00000001` (should match the On-The-Fly mode value written earlier)
    - `[7:0]`  = `00000000` (unused)
  - SPI response expected (MISO):
    ```
    00000001_00000000
    0x0100
    ```

5. **`S_TEST_RD -> S_IDLE`**: If readback matches expected value, setup is complete (`setup_done` is set); otherwise, transitions to `S_ERROR` and sets `boot_fail`.

When `boot_test_skip` is asserted, step 4 is skipped and the core transitions directly from `S_SET_OTF` to `S_IDLE` after asserting `setup_done`.

## Operation

The core operates based on 32-bit command words read from the command buffer. Each command is executed fully before the next is read (except for CANCEL, which can interrupt waits).

### Command Types

- **NO_OP (`3'd0`)**: Delay or trigger wait.
- **SET_ORD (`3'd1`)**: Set sample order for ADC channels.
- **ADC_RD (`3'd2`)**: Read ADC samples.
- **ADC_RD_CH (`3'd3`)**: Read a single ADC channel.
- **CANCEL (`3'd7`)**: Cancel current wait or delay.

### Command Word Structure

- `[31:29]` — Command code (3 bits).
#### NO_OP (`3'd0`)
- `[28]` — **TRIGGER WAIT**: If set, waits for external trigger (`trigger` input); otherwise, uses value as delay timer.
- `[27]` — **CONTINUE**: If set, expects next command immediately after current completes; if not, returns to IDLE unless buffer underflow.
- `[26]` — **REPEAT**: If set, the command is set to be repeated. The repeat count is the next received command buffer word.
- `[24:0]` — **Value**: If TRIGGER WAIT is set, this is the trigger counter (number of triggers to wait for); otherwise, it is the delay timer (number of clock cycles to wait, zero is allowed).

This command does not initiate SPI activity. If TRIGGER WAIT is set, the core waits for the specified number of external trigger events. Otherwise, it waits for the delay timer to expire. The trigger counter represents the exact number of triggers to wait for, so a value of 0 means finish immediately (no triggers), and a value of 1 means wait for one trigger. The core transitions to the next command if present; if CONTINUE is set and there is no next command, it goes to ERROR, otherwise returns to IDLE. If REPEAT is set, the command is set to be repeated. The repeat count is the next received command buffer word. The command is repeated until the count expires.

**State transitions:**
- `S_IDLE -> S_TRIG_WAIT/S_DELAY -> S_IDLE/S_ERROR/next_cmd_state`

#### SET_ORD (`3'd1`)
- `[23:21]` — Channel 7 index
- `[20:18]` — Channel 6 index
- `[17:15]` — Channel 5 index
- `[14:12]` — Channel 4 index
- `[11:9]`  — Channel 3 index
- `[8:6]`   — Channel 2 index
- `[5:3]`   — Channel 1 index
- `[2:0]`   — Channel 0 index

Configures the sample order for subsequent `ADC_RD` commands. The default order is 0 through 7.

**State transitions:**
- `S_IDLE -> S_IDLE/next_cmd_state`

#### ADC_RD (`3'd2`)
- `[28]` — **TRIGGER WAIT**
- `[27]` — **CONTINUE**
- `[26]` — **REPEAT**: If set, the command is set to be repeated. The repeat count is the next received command buffer word.
- `[24:0]` — **Value**: If TRIGGER WAIT is set, this is the trigger counter (number of triggers to wait for) after ADC read; otherwise, it is the delay timer (number of clock cycles to wait after ADC read, zero is allowed).

Initiates an ADC read sequence for 8 channels in the configured order. In On-The-Fly mode, the core sends 8 SPI words of the form `{2'b10, ch, 11'd0}` (where `ch` is the channel index), followed by a dummy word to clock out the last sample, for a total of 9 transactions. Each MISO word returns the sample for the previously requested channel, so the first word is garbage. After all samples are read, the core either waits for the specified number of triggers or delay cycles, depending on the TRIGGER WAIT flag. The trigger counter represents the exact number of triggers to wait for, so a value of 0 means finish immediately (no triggers), and a value of 1 means wait for one trigger. If REPEAT is set, the command is set to be repeated. The repeat count is the next received command buffer word. The command is repeated until the count expires.

**State transitions:**
- `S_IDLE -> S_ADC_RD -> S_TRIG_WAIT/S_DELAY -> S_IDLE/S_ERROR/next_cmd_state`

#### ADC_RD_CH (`3'd3`)
- `[2:0]` — **Channel**: ADC channel to read (0-7)

Immediately and simply reads a single ADC channel. Has no delays or trigger waits after completion. This command always behaves as a trigger-wait command internally, but the wait counter is set to zero so it completes immediately.

**State transitions:**
- `S_IDLE -> S_ADC_RD_CH -> S_IDLE/next_cmd_state`

#### CANCEL (`3'd7`)
- `[28:0]` — Unused.

Cancels the current wait or delay if issued while the core is in DELAY or TRIG_WAIT state (or just finishing ADC_RD, about to transition to one of those). This is the only command that can interrupt a wait. After canceling, the core returns to IDLE.

**State transitions:**
- `S_TRIG_WAIT/S_DELAY/S_ADC_RD -> S_IDLE`

## Data Buffer Output

### ADC Samples

During and shortly after the `S_ADC_RD` state, the core receives 16-bit SIGNED integer ADC samples on MISO. The samples are packed by pairs into 32-bit words for output to the data buffer. For a pair of samples (N, N+1), the output word is formatted as
```
[data_word] = {sample N+1 [15:0], sample N [15:0]}
```

For single-channel reads, the lower 16 bits contain the converted sample and the upper 16 bits are zero.

### Debug Mode
If `debug` is asserted, the core outputs debug information in addition to ADC samples. On a given clock cycle, the core will choose what to output in the following priority order:
1. If an ADC sample pair is ready, output that.
2. If a single ADC sample is ready, output that.
3. If a MISO data word is read during boot test, output a word using Debug Code 1 (`DBG_MISO_DATA`), including the MISO data.
4. If a state transition occurs, output a word using Debug Code 2 (`DBG_STATE_TRANSITION`), including the previous and current state.
5. If a repeat starts, output a word using Debug Code 3 (`DBG_REPEAT_BIT`), including the repeated command and repeat counter.
6. If the chip select timer starts, output a word using Debug Code 4 (`DBG_N_CS_TIMER`), including the timer value.
7. If the SPI bit counter changes from 0 to nonzero, output a word using Debug Code 5 (`DBG_SPI_BIT`), including the SPI bit value.
8. If a command finishes, output a word using Debug Code 6 (`DBG_CMD_DONE`), including the command state and repeat counter.

Debug output format:
- `[31:28]` - Debug Code (see below)
- Remaining bits: debug data (varies by code, see below)

| Debug Code | Name | Data Format |
|:---:|:---|:---|
| 1 | `DBG_MISO_DATA` | `[15:0]` MISO data |
| 2 | `DBG_STATE_TRANSITION` | `[7:4]` prev_state, `[3:0]` state |
| 3 | `DBG_REPEAT_BIT` | `[21:16]` repeated command, `[15:0]` repeat counter |
| 4 | `DBG_N_CS_TIMER` | `[7:0]` n_cs_timer value |
| 5 | `DBG_SPI_BIT` | `[4:0]` spi_bit value |
| 6 | `DBG_CMD_DONE` | `[22]` next_cmd_ready, `[21:16]` command bits, `[15:0]` repeat counter |

If none of the above conditions are met, the output word is zero and nothing is written to the data buffer.

## Errors

- Boot readback mismatch (`boot_fail`)
- Unexpected trigger (trigger when not in `S_TRIG_WAIT`) (`unexp_trig`)
- Delay too short (`delay_too_short`)
- Invalid commands (`bad_cmd`)
- Buffer underflow (expect next command with command buffer empty) (`cmd_buf_underflow`)
- Underflow while starting a repeat (`cmd_buf_underflow`)
- Buffer overflow (try to write to data buffer with data buffer full) (`data_buf_overflow`)

## Notes

- SPI timing and chip select are managed to meet ADS816x requirements.
- The `n_cs_high_time` input is latched when the state machine is in `S_RESET` and clamped to a minimum of 3 cycles.
- The `min_delay_time` input is latched when the state machine is in `S_RESET` and clamped to a minimum of 171 cycles.
- Asynchronous FIFO and synchronizer modules are used for safe cross-domain data transfer.
- Data buffer output is packed as two samples per 32-bit word.

## References

- [ADS8168 Datasheet](https://www.ti.com/product/ADS8168)
- [ADS8167 Datasheet](https://www.ti.com/product/ADS8167)
- [ADS8166 Datasheet](https://www.ti.com/product/ADS8166)

---
*See the source code for detailed implementation and signal descriptions.*

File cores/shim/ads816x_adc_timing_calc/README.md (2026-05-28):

***Updated 2025-09-21***
# ADS816x ADC Timing Calculator Core

The `ads816x_adc_timing_calc` module provides hardware-optimized timing calculations for ADS816x series ADCs, determining the required n_cs high time based on SPI clock frequency and ADC model specifications.

## Overview

This module calculates the minimum number of SPI clock cycles that the chip select (n_cs) signal must remain high between ADC conversions to meet timing requirements. The calculation considers both conversion time and cycle time constraints for different ADS816x models. To divide, the module scales the nanosecond timing requirements to a power-of-two unit (NiS) to allow division via bit-shifting. The output represents cycles minus 1 (i.e., output of 3 means 4 actual cycles).

## Parameters

| Parameter | Type | Default | Description | Valid Values |
|:---|:---|:---|:---|:---|
| `ADS_MODEL_ID` | integer | 8 | ADC model identifier for timing selection | 6 (ADS8166), 7 (ADS8167), 8 (ADS8168) |

## ADC Model Specifications

| Model | Conversion Time | Cycle Time | NiS Conv | NiS Cycle | Bit Width Conv | Bit Width Cycle |
|:---|:---:|:---:|:---:|:---:|:---:|:---:|
| ADS8168  | 660 ns | 1000 ns | 709 | 1074 | 10 bits | 11 bits |
| ADS8167  | 1200 ns | 2000 ns | 1289 | 2148 | 11 bits | 12 bits |
| ADS8166  | 2500 ns | 4000 ns | 2685 | 4295 | 12 bits | 13 bits |

*NiS (Like GiB vs GB) units: 2^30 NiS = 10^9 NS = 1 second*

## Interface

### Inputs
- `clk`: System clock signal
- `resetn`: Active-low reset signal
- `spi_clk_freq_hz` (32-bit): SPI clock frequency in Hz
- `calc`: Start calculation signal (active high)

### Outputs
- `n_cs_high_time` (8-bit): Calculated n_cs high time in SPI clock cycles minus 1 (2-255, representing 3-256 actual cycles)
- `done`: Calculation complete signal (active high)
- `lock_viol`: Lock violation signal, asserted if SPI frequency changes during calculation

## Operation

### State Machine
The module implements a 5-state finite state machine:

1. **S_IDLE (0)**: Waiting for calculation request
2. **S_CALC_CONV (1)**: Calculate minimum cycles for conversion time
3. **S_CALC_CYCLE (2)**: Calculate minimum cycles for cycle time
4. **S_CALC_RESULT (3)**: Determine final result from both calculations
5. **S_DONE (4)**: Output final result and wait for calc deassertion

### Calculation Method

The module uses optimized shift-add multiplication to avoid DSP resource usage and includes automatic rounding:

1. **Conversion Time Calculation**:
   ```
   min_cycles_conv = max(3, (T_CONV_NiS × spi_clk_freq_hz + 2^30 - 1) >> 30)
   ```

2. **Cycle Time Calculation**:
   ```
   min_cycles_cycle = max(0, ((T_CYCLE_NiS × spi_clk_freq_hz + 2^30 - 1) >> 30) - 16)
   ```
   *Note: 16 represents the on-the-fly command bits*

3. **Final Result**:
   ```
   n_cs_high_time = min(255, max(min_cycles_conv, min_cycles_cycle) - 1)
   ```
   *Note: Output is cycles minus 1, so actual cycles = n_cs_high_time + 1*

### Performance Optimizations

- **NiS Scaling**: Uses 2^30 scaling factor to replace division with bit shifting
- **Automatic Rounding**: Adds 2^30 - 1 before bit shifting to ensure proper rounding up
- **Optimized Multiplication**: Shift-add algorithm iterates only for significant bits:
  - ADS8168: 10-11 iterations instead of 32
  - ADS8167: 11-12 iterations instead of 32
  - ADS8166: 12-13 iterations instead of 32
- **Resource Efficient**: Uses wire for intermediate rounding calculations, no DSP blocks required

### Error Handling

- **Lock Violation**: If `spi_clk_freq_hz` changes during calculation, `lock_viol` is asserted and the state machine returns to idle
- **Early Termination**: If `calc` signal is deasserted during calculation, the module returns to idle state
- **Saturation**: Output is capped at 255 cycles maximum

### Timing Constraints

- **Minimum Conversion Time**: Ensures at least 3 cycles for conversion
- **Cycle Time Accounting**: Subtracts 16-bit command transmission time from cycle requirement
- **Output Format**: Returns cycles minus 1 (actual cycles = output + 1, range 3-256 cycles)
- **Maximum Frequency**: At 50MHz SPI clock with output 255, actual cycles are 256, total time is 5440ns (exceeds maximum 4000ns ADC requirement)

## Usage Example

```systemverilog
// Instantiate ADS8168 timing calculator
ads816x_adc_timing_calc #(
    .ADS_MODEL_ID(8)  // ADS8168
) adc_timing_calc (
    .clk(clk),
    .resetn(resetn),
    .spi_clk_freq_hz(32'd20_000_000),  // 20MHz SPI clock
    .calc(start_calc),
    .n_cs_high_time(cs_high_cycles),
    .done(calc_done),
    .lock_viol(freq_changed)
);
```

## Implementation Notes

- All timing constants are compile-time parameters based on `ADS_MODEL_ID`
- Multiplication optimization reduces calculation time by ~50%
- Module maintains frequency lock during calculation to ensure accuracy
- Reset values initialize all registers to safe defaults
- **Output Format**: n_cs_high_time represents cycles minus 1 for hardware efficiency
- Automatic rounding ensures conservative timing calculations

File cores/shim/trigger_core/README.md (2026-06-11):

**Updated 2026-06-08**
# Trigger Core (`trigger_core`)

The `trigger_core` module provides command-driven trigger orchestration for the Rev D shim firmware. It can synchronize ADC/DAC trigger consumers, gate external triggers with a programmable lockout, generate forced triggers, and optionally log trigger timestamps.

## Parameters

- `TRIGGER_LOCKOUT_DEFAULT`: Default external-trigger lockout in `clk` cycles.
  - Valid range is 4 to `28'hFFFFFFF`.
  - Values outside this range raise a simulation-time `$error`.

## Inputs and Outputs

### Inputs

- `clk`, `resetn`: Main clock and active-low reset.
- `cmd_word [31:0]`: Command word from command FIFO.
- `cmd_buf_empty`: Command FIFO empty flag.
- `data_buf_full`: Data FIFO full flag.
- `data_buf_almost_full`: Data FIFO almost-full flag. This is used to guarantee room for two log words.
- `ext_trig`: External trigger input (internally synchronized with a 2-flop synchronizer).
- `dac_waiting_for_trig [7:0]`: Per-channel DAC waiting flags.
- `adc_waiting_for_trig [7:0]`: Per-channel ADC waiting flags.

### Outputs

- `cmd_word_rd_en`: Command FIFO read strobe.
- `data_word_wr_en`: Data FIFO write strobe.
- `data_word [31:0]`: Trigger log payload.
- `trig_out`: One-cycle internal trigger pulse output.
- `trig_counter [31:0]`: Trigger event count.
- `data_buf_overflow`: Sticky overflow flag when logging cannot write two words.
- `bad_cmd`: Sticky invalid-command/invalid-argument flag.

## Command Encoding

- `[31:29]`: Command type.
- `[28]`: Log-enable bit for trigger-producing commands.
- `[27:0]`: Command value.

### Command Types

- `SYNC_CH (3'd1)`
  - Waits until all `dac_waiting_for_trig` bits and all `adc_waiting_for_trig` bits are high.
  - Emits one trigger pulse when all channels are ready.
  - If already ready, can complete immediately and still trigger.
  - If log-enable is set, this trigger is logged.

- `SET_LOCKOUT (3'd2)`
  - Sets the external-trigger lockout period to `[27:0]`.
  - Values below 4 are rejected and push the FSM to `S_ERROR` (sets `bad_cmd`).

- `EXPECT_EXT_TRIG (3'd3)`
  - Arms external-trigger counting for `[27:0]` events.
  - 0 is special: it does not arm counting and is treated as "infinite" (will not complete based on count exhaustion, only by `CANCEL`).
  - Each accepted external trigger decrements the internal counter and emits `trig_out`.
  - If log-enable is set, each accepted trigger is logged.

- `DELAY (3'd4)`
  - Waits `[27:0]` clock cycles.
  - A value of 0 completes immediately (next cycle will be the next command).

- `FORCE_TRIG (3'd5)`
  - Emits an immediate trigger pulse.
  - If log-enable is set, this trigger is logged.

- `RESET_COUNT (3'd6)`
  - Resets `trig_counter` and the internal 64-bit timestamp counter.
  - This command has side effects as soon as it reaches the FIFO head (`cmd_word_rd_en` also asserts on this command).

- `CANCEL (3'd7)`
  - Can cancel active waits and complete commands from any non-error state.
  - Causes command completion and transition back to `S_IDLE`.

## State Machine

The FSM states are:

- `S_RESET (0)`: Reset state.
- `S_IDLE (1)`: Wait for next command.
- `S_SYNC_CH (2)`: Wait for all ADC/DAC channels to be ready for sync trigger.
- `S_EXPECT_TRIG (3)`: Wait for programmed number of accepted external triggers.
- `S_DELAY (4)`: Delay countdown.
- `S_ERROR (5)`: Error state.

`cmd_done` is asserted for:

- command available in `S_IDLE`
- sync complete in `S_SYNC_CH`
- external-trigger count exhausted in `S_EXPECT_TRIG`
- delay counter exhausted in `S_DELAY`
- `CANCEL` command from any non-error state

## Trigger Generation and Lockout

Triggers are produced by:

- `FORCE_TRIG`
- `SYNC_CH` completion
- accepted external trigger events in `S_EXPECT_TRIG`

External-trigger acceptance requires:

- `state == S_EXPECT_TRIG`
- `ext_trig_counter > 0`
- `lockout_counter == 0`
- synchronized `ext_trig` high

After each accepted external trigger, `lockout_counter` reloads from `trig_lockout` and counts down to prevent rapid retriggering.

## Logging Format

If a trigger event has logging enabled (`do_log`), two FIFO words are written in consecutive cycles:

1. lower 32 bits of internal 64-bit timer
2. upper 32 bits of internal 64-bit timer

Writes are attempted only when both `data_buf_full == 0` and `data_buf_almost_full == 0`. Otherwise `data_buf_overflow` is set.

## Counters and Timer

- `trig_counter` increments on every emitted trigger (`trig_out` event source).
- `trig_counter` resets on `RESET_COUNT` or global reset.
- internal 64-bit timer:
  - resets on global reset and `RESET_COUNT`
  - starts at 1 on first logged trigger
  - increments each cycle while nonzero, saturating at `64'hFFFFFFFFFFFFFFFF`

## Error Handling

- `bad_cmd` is set when:
  - command decode is invalid, or
  - `SET_LOCKOUT` value is below minimum (4)
- `data_buf_overflow` is set when a log event occurs and FIFO cannot accept two words

Both flags are sticky until reset.

## Notes

- Command FIFO read behavior is intentional: `cmd_word_rd_en = do_next_cmd || reset_count`.
- `CANCEL` is allowed broadly (any non-error state), not just delay/expect states.
- External trigger detection is level-sensitive after synchronization, with lockout preventing immediate retriggering.

---
*See source code for detailed implementation and signal descriptions.*

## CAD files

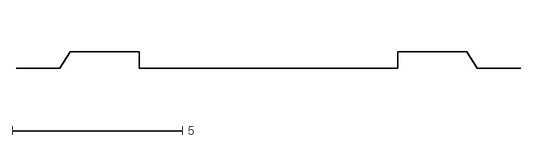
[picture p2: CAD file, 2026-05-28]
docs/dxf_waveforms/dxf/line_7.dxf
14.8 x 0.49

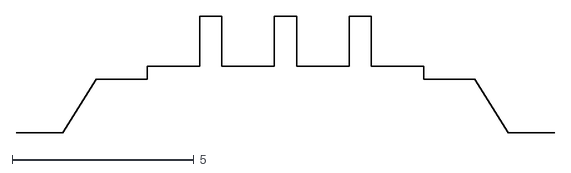
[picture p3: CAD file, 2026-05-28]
docs/dxf_waveforms/dxf/line_4.dxf
14.8 x 3.21

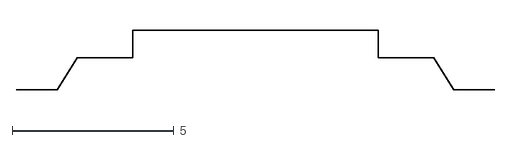
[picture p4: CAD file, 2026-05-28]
docs/dxf_waveforms/dxf/line_6.dxf
14.8 x 1.83

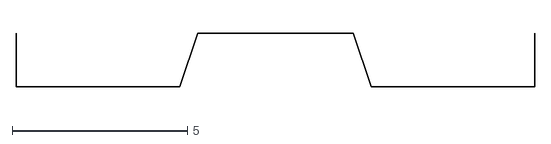
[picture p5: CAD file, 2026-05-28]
docs/dxf_waveforms/dxf/line_8.dxf
14.8 x 1.53

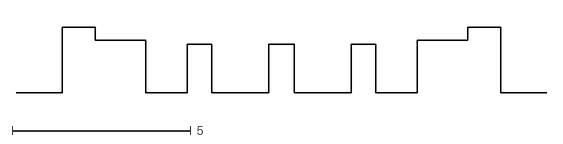
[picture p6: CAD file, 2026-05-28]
docs/dxf_waveforms/dxf/line_5.dxf
14.8 x 1.83

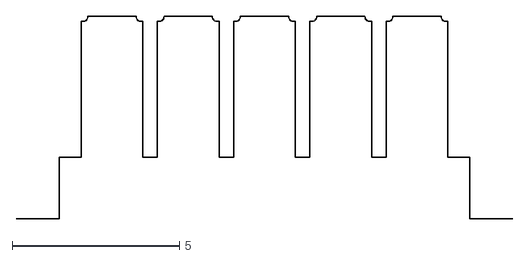
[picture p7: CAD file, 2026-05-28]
docs/dxf_waveforms/dxf/line_3.dxf
14.8 x 6.04

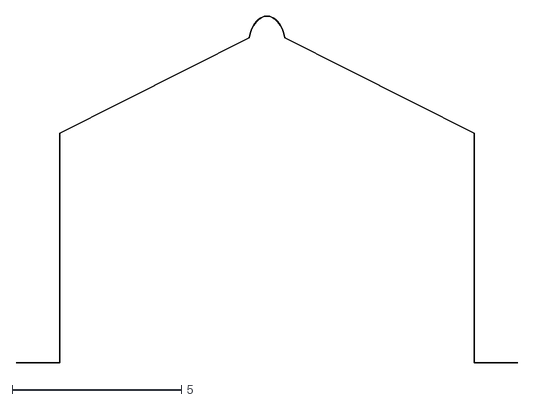
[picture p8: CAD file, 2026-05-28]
docs/dxf_waveforms/dxf/line_1.dxf
14.8 x 10.3

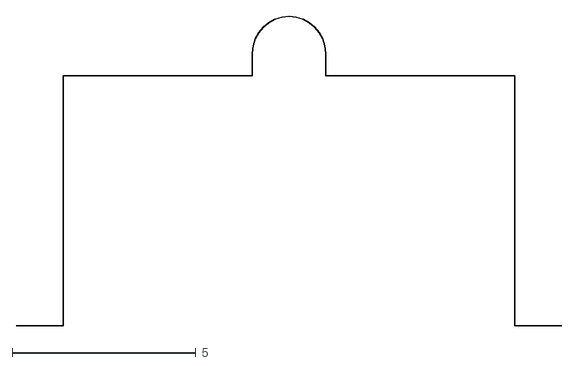
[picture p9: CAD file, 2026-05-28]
docs/dxf_waveforms/dxf/line_2.dxf
14.8 x 8.40

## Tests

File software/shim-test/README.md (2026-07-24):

# shim-test

`shim-test` is an interactive command-line tool for manually testing every aspect of the Rev D shim amplifier driver. It maps the shim hardware into memory and initializes control/status interfaces for the system, SPI clock, DACs, ADCs, and trigger, then drops into a REPL-style command loop.

From that prompt you can exercise and inspect all parts of the driver by hand — configuring and controlling the system, driving the DACs, reading the ADCs, and working with the trigger and streaming/experiment features — making it useful for bring-up, debugging, and validation.

## Usage

```bash
shim-test [--verbose]
```

Type `help` at the `Command>` prompt to list all available commands.

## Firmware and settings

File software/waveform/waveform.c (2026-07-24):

//  waveform.c
//
//  Usage:
//    waveform <file.csv> [--adc <path> | -a <path>] [--lockout <float> | -l <float>]
//    [--clk_MHz <float> | -c <float>] [--iters <int> | -i <int>] [--help | -h]
//
//  <file.csv> is a required positional argument.
//  All flags are optional and have defaults:
//    --adc, -a      (string)  default: none (unset)
//    --lockout, -l  (double)  default: 10.0
//    --clk_MHz, -c  (double)  default: 30.0
//    --iters, -i    (int)     default: 1
//    --help, -h     

#include <stdio.h>
#include <stdlib.h>
#include <string.h>
#include <getopt.h>
#include <errno.h>
#include <limits.h>
#include <signal.h>
#include <pthread.h>
#include <stdbool.h>
#include <unistd.h>

#include "waveform_file_handling.h"
#include "waveform_hw.h"

typedef struct {
  const char *input_file;  // required positional argument
  const char *adc_file;    // --adc, default: NULL (none)
  double lockout;          // --lockout, default: 10.0
  double clk_MHz;          // --clk_MHz, default: 30.0
  int iters;               // --iters, default: 1
} config_t;

// Set from the signal handler (async-signal-safe) and polled by the main
// monitor loop, which performs the actual stop-request + hardware power-off
// from normal thread context. A volatile sig_atomic_t is the only state the
// handler may safely touch.
static volatile sig_atomic_t g_stop_requested = 0;

static void print_usage(const char *prog) {
  fprintf(stderr,
    "Usage: %s <file.csv> [OPTIONS]\n"
    "\n"
    "Required:\n"
    "  <file.csv>            Input file path\n"
    "\n"
    "Options:\n"
    "  -a, --adc <path>          ADC file path (default: none)\n"
    "  -l, --lockout <float>     Lockout value in ms (default: 10.0)\n"
    "  -c, --clk_MHz <float>     Clock value (MHz, default: 30.0)\n"
    "  -i, --iters <int>         Number of iterations (default: 1)\n"
    "  -h, --help                Show this help message\n",
    prog);
}

// Parse a double from a string, exiting with an error on failure.
static double parse_double_arg(const char *flag, const char *val) {
  char *end;
  errno = 0;
  double d = strtod(val, &end);
  if (errno != 0 || end == val || *end != '\0') {
    fprintf(stderr, "Error: invalid value for %s: '%s'\n", flag, val);
    exit(EXIT_FAILURE);
  }
  return d;
}

// Parse an int from a string, exiting with an error on failure.
static int parse_int_arg(const char *flag, const char *val) {
  char *end;
  errno = 0;
  long l = strtol(val, &end, 10);
  if (errno != 0 || end == val || *end != '\0') {
    fprintf(stderr, "Error: invalid value for %s: '%s'\n", flag, val);
    exit(EXIT_FAILURE);
  }
  return (int)l;
}

// Copy src into dst, dropping the trailing filename extension if one exists
// (the last '.' in the final path component). "test.csv" -> "test",
// "archive.tar.gz" -> "archive.tar", "noext" -> "noext". dst must hold at
// least PATH_MAX bytes.
static void strip_extension(char *dst, size_t dst_size, const char *src) {
  snprintf(dst, dst_size, "%s", src);
  char *slash = strrchr(dst, '/');
  char *dot = strrchr(dst, '.');
  // Only trim when the dot belongs to the final path component and isn't a
  // leading dot (e.g. a dotfile like ".config" has no extension to drop).
  if (dot != NULL && (slash == NULL || dot > slash + 1) &&
      (slash == NULL || dot != slash + 1)) {
    *dot = '\0';
  }
}

// --- Signal handling ---------------------------------------------------

// Handler for SIGINT/SIGTERM: only record that a stop was requested. Everything
// that is unsafe to do from signal context -- locking thread mutexes, powering
// off the hardware, printing -- is done by the main thread once it observes
// this flag.
static void handle_stop_signal(int signum) {
  (void)signum;
  g_stop_requested = 1;
}

// Print a one-line notice (flushed immediately so it doesn't interleave with
// other output) when a stream thread finishes, noting whether it ran to
// completion or stopped early. Called from the main monitor thread so the
// prints stay serialized.
static void print_stream_finished(const char *name, bool stopped_early) {
  if (stopped_early) {
    printf("[%s] stream stopped early\n", name);
  } else {
    printf("[%s] stream finished\n", name);
  }
  fflush(stdout);
}

// Start both ADC streams -- the command stream and the data (output) stream --
// together, since the data stream only runs while the command stream does. On
// success both threads are running and *cmd_tid / *data_tid are set, and it
// returns 0. On failure it prints an error, makes sure no ADC thread is left
// running (joining the command thread if the data thread failed to start), and
// returns -1 so the caller can clean up the rest.
static int start_adc_streams(adc_cmd_file_info_t *cmd_info, adc_data_file_info_t *data_info,
                             pthread_t *cmd_tid, pthread_t *data_tid) {
  if (pthread_create(cmd_tid, NULL, adc_cmd_stream_thread, cmd_info) != 0) {
    fprintf(stderr, "Error: failed to start ADC command stream thread\n");
    return -1;
  }
  if (pthread_create(data_tid, NULL, adc_data_stream_thread, data_info) != 0) {
    fprintf(stderr, "Error: failed to start ADC data stream thread\n");
    adc_cmd_file_info_request_stop(cmd_info);
    pthread_join(*cmd_tid, NULL);
    return -1;
  }
  return 0;
}

int main(int argc, char *argv[]) {
  config_t cfg = {
    .input_file = NULL,
    .adc_file   = NULL,
    .lockout    = 10.0,
    .clk_MHz    = 30.0,
    .iters      = 1
  };

  static struct option long_options[] = {
    {"adc",     required_argument, 0, 'a'},
    {"lockout", required_argument, 0, 'l'},
    {"clk_MHz", required_argument, 0, 'c'},
    {"iters",   required_argument, 0, 'i'},
    {"help",    no_argument,       0, 'h'},
    {0, 0, 0, 0}
  };

  int opt;
  int option_index = 0;

  // Default (permute) mode: getopt_long reorders argv so all flags are
  //  handled here, leaving any positional arguments at the end for us
  //  to read via optind below.
  while ((opt = getopt_long(argc, argv, "ha:l:c:i:", long_options, &option_index)) != -1) {
    switch (opt) {
      case 'a':
      cfg.adc_file = optarg;
      break;
      case 'l':
      cfg.lockout = parse_double_arg("--lockout", optarg);
      break;
      case 'c':
      cfg.clk_MHz = parse_double_arg("--clk_MHz", optarg);
      break;
      case 'i':
      cfg.iters = parse_int_arg("--iters", optarg);
      break;
      case 'h':
      print_usage(argv[0]);
      return EXIT_SUCCESS;
      default:
      print_usage(argv[0]);
      return EXIT_FAILURE;
    }
  }

  // After flag parsing, optind points at the first non-flag argument.
  if (optind >= argc) {
    fprintf(stderr, "Error: missing required <file.csv> argument\n");
    print_usage(argv[0]);
    return EXIT_FAILURE;
  }
  cfg.input_file = argv[optind];

  if (optind + 1 < argc) {
    fprintf(stderr, "Error: unexpected extra argument '%s'\n", argv[optind + 1]);
    print_usage(argv[0]);
    return EXIT_FAILURE;
  }

  if (cfg.iters < 1) {
    fprintf(stderr, "Error: --iters must be >= 1 (got %d)\n", cfg.iters);
    return EXIT_FAILURE;
  }

  printf("input_file = %s\n", cfg.input_file);
  printf("adc_file   = %s\n", cfg.adc_file ? cfg.adc_file : "(none)");
  printf("lockout    = %g\n", cfg.lockout);
  printf("clk_MHz    = %g\n", cfg.clk_MHz);
  printf("iters      = %d\n", cfg.iters);

  // --- Validate the input (DAC) file ------------------------------
  waveform_file_info_t input_info;
  if (validate_input_file(cfg.input_file, &input_info) != 0) {
    return EXIT_FAILURE;
  }
  printf("Input file OK: %d channel(s), %ld row(s), %ld trigger point(s), current range [%g, %g] A\n",
         input_info.num_channels, input_info.num_rows, input_info.num_trigs,
         input_info.min_current, input_info.max_current);
  input_info.iters = cfg.iters;

  // --- Initialize hardware pointers and check that enough boards/FIFOs are present
  hw_t hw = hw_init(input_info.num_channels, cfg.clk_MHz, false);

  // --- Validate the ADC file, if provided -------------------------
  adc_cmd_file_info_t adc_info;
  bool has_adc_info = false;
  if (cfg.adc_file != NULL) {
    if (validate_adc_file(cfg.adc_file, input_info.num_trigs, &adc_info) != 0) {
      return EXIT_FAILURE;
    }
    has_adc_info = true;
    adc_info.iters = cfg.iters;
    printf("ADC file OK: %ld trigger point(s) match the input file\n", adc_info.num_trigs);
  }

  // --- Catch SIGINT/SIGTERM so we can power off the hardware before exiting -
  struct sigaction sa;
  memset(&sa, 0, sizeof(sa));
  sa.sa_handler = handle_stop_signal;
  sigemptyset(&sa.sa_mask);
  sigaction(SIGINT, &sa, NULL);
  sigaction(SIGTERM, &sa, NULL);

  // --- Bring up the hardware ---------------------------------------
  if (hw_power_on(&hw) != 0) {
    fprintf(stderr, "Error: failed to power on hardware\n");
    return EXIT_FAILURE;
  }

  if (!hw_running(&hw)) {
    fprintf(stderr, "Error: hardware is not running\n");
    hw_power_off(&hw);
    return EXIT_FAILURE;
  }


  if (hw_set_trigger_lockout(&hw, cfg.lockout) != 0) {
    fprintf(stderr, "Error: failed to set trigger lockout to %g ns\n", cfg.lockout);
    hw_power_off(&hw);
    return EXIT_FAILURE;
  }

  // --- Validate timing using the min dt values gathered earlier ----
  if (!hw_dac_timing_valid(&hw, input_info.min_dt)) {
    fprintf(stderr, "Error: DAC timing is invalid for min dt = %g\n", input_info.min_dt);
    hw_power_off(&hw);
    return EXIT_FAILURE;
  }
  if (has_adc_info && !hw_adc_timing_valid(&hw, adc_info.min_dt)) {
    fprintf(stderr, "Error: ADC timing is invalid for min dt = %g\n", adc_info.min_dt);
    hw_power_off(&hw);
    return EXIT_FAILURE;
  }

  // --- Start the stream threads ------------------------------------
  pthread_t dac_tid, adc_tid, adc_data_tid, trigger_tid;
  trigger_file_info_t trigger_arg;
  adc_data_file_info_t adc_data_info;
  bool has_adc_thread = false;
  bool has_adc_data_thread = false;

  // Output CSV paths, derived from the input file name with its extension
  // trimmed (so "test.csv" yields "test.trig_t_sec.csv", not
  // "test.csv.trig_t_sec.csv").
  char input_stem[PATH_MAX];
  char adc_out_path[PATH_MAX];
  char trig_out_path[PATH_MAX];
  strip_extension(input_stem, sizeof(input_stem), cfg.input_file);

  trigger_file_info_init(&trigger_arg, "Trigger", input_info.num_trigs, cfg.iters);

  input_info.hw = &hw;
  trigger_arg.hw = &hw;
  // The trigger data stream writes one trigger time (in seconds) per line.
  snprintf(trig_out_path, sizeof(trig_out_path), "%s.trig_t_sec.csv", input_stem);
  trigger_arg.path = trig_out_path;
  if (has_adc_info) {
    adc_info.hw = &hw;
    // The ADC data stream drains one sample per ADC read command and writes the
    // active-channel amps (comma-separated) as one line per sample.
    adc_data_file_info_init(&adc_data_info, adc_info.num_rows, cfg.iters);
    adc_data_info.hw = &hw;
    snprintf(adc_out_path, sizeof(adc_out_path), "%s.adc_out_A.csv", input_stem);
    adc_data_info.path = adc_out_path;
  }

  // Block SIGINT/SIGTERM while spawning the stream threads so they inherit a
  // blocked mask and never take the signal themselves. It is unblocked again
  // below, once the threads are running, so a stop signal is delivered only to
  // the main thread -- keeping the handler off the worker threads and their
  // mutexes.
  sigset_t stop_signals;
  sigemptyset(&stop_signals);
  sigaddset(&stop_signals, SIGINT);
  sigaddset(&stop_signals, SIGTERM);
  pthread_sigmask(SIG_BLOCK, &stop_signals, NULL);

  if (pthread_create(&dac_tid, NULL, dac_stream_thread, &input_info) != 0) {
    fprintf(stderr, "Error: failed to start DAC stream thread\n");
    waveform_file_info_destroy(&input_info);
    if (has_adc_info) {
      adc_cmd_file_info_destroy(&adc_info);
      adc_data_file_info_destroy(&adc_data_info);
    }
    trigger_file_info_destroy(&trigger_arg);
    hw_power_off(&hw);
    return EXIT_FAILURE;
  }

  if (has_adc_info) {
    // The ADC command stream and its data (output) stream are launched together.
    if (start_adc_streams(&adc_info, &adc_data_info, &adc_tid, &adc_data_tid) != 0) {
      waveform_file_info_request_stop(&input_info);
      waveform_file_info_destroy(&input_info);
      adc_cmd_file_info_destroy(&adc_info);
      adc_data_file_info_destroy(&adc_data_info);
      trigger_file_info_destroy(&trigger_arg);
      hw_power_off(&hw);
      return EXIT_FAILURE;
    }
    has_adc_thread = true;
    has_adc_data_thread = true;
  }

  if (pthread_create(&trigger_tid, NULL, trigger_stream_thread, &trigger_arg) != 0) {
    fprintf(stderr, "Error: failed to start trigger stream thread\n");
    waveform_file_info_request_stop(&input_info);
    if (has_adc_thread) {
      adc_cmd_file_info_request_stop(&adc_info);
    }
    if (has_adc_data_thread) {
      adc_data_file_info_request_stop(&adc_data_info);
    }
    waveform_file_info_destroy(&input_info);
    if (has_adc_info) {
      adc_cmd_file_info_destroy(&adc_info);
      adc_data_file_info_destroy(&adc_data_info);
    }
    trigger_file_info_destroy(&trigger_arg);
    hw_power_off(&hw);
    return EXIT_FAILURE;
  }

  // The stream threads are running; unblock SIGINT/SIGTERM so a stop signal is
  // delivered to (and handled only by) the main thread from here on.
  pthread_sigmask(SIG_UNBLOCK, &stop_signals, NULL);

  // --- Start the expected number of triggers ------------------------
  long expected_triggers = (long)cfg.iters * input_info.num_trigs;
  hw_start_triggers(&hw, expected_triggers);

  // --- Monitor progress ----------------------------------------------
  // Poll the hardware trigger counter while the stream threads are running.
  uint32_t last_trigger_count = 0;
  printf("[HW] polling hardware trigger count\n");

  // Let each stream thread run to completion on its own; we just poll their
  // state here. (A stop can still be requested externally, e.g. from the
  // signal handler.)
  bool dac_done = false;
  bool adc_done = false;
  bool adc_data_done = false;
  bool trigger_done = false;
  bool any_stopped_early = false;
  bool stop_all_requested = false;
  while (!dac_done || (has_adc_thread && !adc_done) ||
         (has_adc_data_thread && !adc_data_done) || !trigger_done) {
    // A stop signal (CTRL+C / SIGTERM): stop polling and fall through to the
    // join + power-off below.
    if (g_stop_requested) {
      break;
    }
    if (!dac_done && waveform_file_info_is_finished(&input_info)) {
      dac_done = true;
      bool early = waveform_file_info_stopped_early(&input_info);
      if (early) {
        any_stopped_early = true;
      }
      print_stream_finished("DAC", early);
    }
    if (has_adc_thread && !adc_done && adc_cmd_file_info_is_finished(&adc_info)) {
      adc_done = true;
      bool early = adc_cmd_file_info_stopped_early(&adc_info);
      if (early) {
        any_stopped_early = true;
      }
      print_stream_finished("ADC", early);
    }
    if (has_adc_data_thread && !adc_data_done && adc_data_file_info_is_finished(&adc_data_info)) {
      adc_data_done = true;
      bool early = adc_data_file_info_stopped_early(&adc_data_info);
      if (early) {
        any_stopped_early = true;
      }
      print_stream_finished("ADC data", early);
    }
    if (!trigger_done && trigger_file_info_is_finished(&trigger_arg)) {
      trigger_done = true;
      bool early = trigger_file_info_stopped_early(&trigger_arg);
      if (early) {
        any_stopped_early = true;
      }
      print_stream_finished("Trigger", early);
    }

    // If a thread ended early on its own (a hardware error -- a stop signal is
    // handled by the g_stop_requested break above), ask the rest to stop too so
    // they don't keep streaming into a system that is about to be powered off.
    if (any_stopped_early && !stop_all_requested) {
      fprintf(stderr, "Error: a stream thread stopped early; stopping the others\n");
      waveform_file_info_request_stop(&input_info);
      if (has_adc_thread) {
        adc_cmd_file_info_request_stop(&adc_info);
      }
      if (has_adc_data_thread) {
        adc_data_file_info_request_stop(&adc_data_info);
      }
      trigger_file_info_request_stop(&trigger_arg);
      stop_all_requested = true;
    }

    uint32_t current_trigger_count = hw_get_trigger_count(&hw);
    if (current_trigger_count != last_trigger_count) {
      // Report progress against the just-counted trigger. current_trigger_count
      // is the number of completed triggers (>= 1 here), so its 0-based index
      // (count - 1) maps to the iteration and the trigger within that iteration
      // that just fired -- avoiding rolling over to the next iteration when a
      // full iteration's worth of triggers completes.
      uint32_t completed = current_trigger_count - 1;
      uint32_t iteration = completed / input_info.num_trigs;
      uint32_t trigger_in_iteration = completed % input_info.num_trigs;
      printf("[HW] trigger count: %u / %ld (iteration %u / %d, trigger %u / %ld)\n",
             current_trigger_count, expected_triggers,
             iteration + 1, cfg.iters, trigger_in_iteration + 1, input_info.num_trigs);
      fflush(stdout);
      last_trigger_count = current_trigger_count;
    }

    if (!dac_done || (has_adc_thread && !adc_done) ||
        (has_adc_data_thread && !adc_data_done) || !trigger_done) {
      usleep(500000); // Sleep for 500 ms before polling again
    }
  }

  // If we left the loop because of CTRL+C, threads may still be running; ask
  // them all to stop so the joins below return promptly.
  if (g_stop_requested) {
    waveform_file_info_request_stop(&input_info);
    if (has_adc_thread) {
      adc_cmd_file_info_request_stop(&adc_info);
    }
    if (has_adc_data_thread) {
      adc_data_file_info_request_stop(&adc_data_info);
    }
    trigger_file_info_request_stop(&trigger_arg);
  }

  // --- Join stream threads now that each has reported finished ------
  pthread_join(dac_tid, NULL);
  if (has_adc_thread) {
    pthread_join(adc_tid, NULL);
  }
  if (has_adc_data_thread) {
    pthread_join(adc_data_tid, NULL);
  }
  pthread_join(trigger_tid, NULL);

  // --- Power off hardware and exit -----------------------------------
  waveform_file_info_destroy(&input_info);
  if (has_adc_info) {
    adc_cmd_file_info_destroy(&adc_info);
    adc_data_file_info_destroy(&adc_data_info);
  }
  trigger_file_info_destroy(&trigger_arg);
  hw_power_off(&hw);

  if (g_stop_requested) {
    fprintf(stderr, "Interrupted by signal; hardware powered off\n");
    return EXIT_FAILURE;
  }
  if (any_stopped_early) {
    fprintf(stderr, "Error: one or more stream threads stopped early\n");
    return EXIT_FAILURE;
  }
  printf("Done.\n");

  return EXIT_SUCCESS;
}

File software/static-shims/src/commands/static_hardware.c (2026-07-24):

#include <stdio.h>
#include <stdlib.h>
#include <unistd.h>

#include "static_hardware.h"

// Linearity status for channel calibration
typedef enum {
    LINEARITY_LINEAR = 0,     // Good linearity, calibration successful
    LINEARITY_ZERO = 1,       // Slope is constant near zero (likely disconnected)
    LINEARITY_NONLINEAR = 2   // Slope outside acceptable range (likely oscillations)
} linearity_status_t;

// Initialize and validate hardware control structure for a given channel count. Exits on failure
hw_t hw_init(uint32_t channel_count, bool verbose) {
  hw_t hw;

  if (channel_count < 1 || channel_count > HW_MAX_CHANNELS) {
    fprintf(stderr, "Error: channel_count %u is out of supported range (1-%u).\n", channel_count, HW_MAX_CHANNELS);
    exit(1);
  }

  hw.channel_count = channel_count;
  hw.verbose = verbose;

  // Initialize all hardware control structures
  hw.sys_ctrl     = create_sys_ctrl(verbose);
  hw.clk_ctrl     = create_clk_ctrl(verbose);
  hw.sys_sts      = create_sys_sts(verbose);
  hw.dac_ctrl     = create_dac_ctrl(verbose);
  hw.adc_ctrl     = create_adc_ctrl(verbose);
  hw.trigger_ctrl = create_trigger_ctrl(verbose);

  // Check that enough FIFOs are configured in hardware for the requested channel count
  for (uint32_t i = 0; i < ((channel_count - 1) / 8 + 1); i++) {
    if (verbose) {
      printf("Checking FIFO connections for board %u...\n", i);
    }
    if (!FIFO_PRESENT(sys_sts_get_dac_cmd_fifo_status(&hw.sys_sts, i, verbose))) {
      fprintf(stderr, "Error: DAC command FIFO for board %u is not present. Channel count may be too high for hardware configuration.\n", i);
      exit(1);
    }
    if (!FIFO_PRESENT(sys_sts_get_dac_data_fifo_status(&hw.sys_sts, i, verbose))) {
      fprintf(stderr, "Error: DAC data FIFO for board %u is not present. Channel count may be too high for hardware configuration.\n", i);
      exit(1);
    }
    if (!FIFO_PRESENT(sys_sts_get_adc_cmd_fifo_status(&hw.sys_sts, i, verbose))) {
      fprintf(stderr, "Error: ADC command FIFO for board %u is not present. Channel count may be too high for hardware configuration.\n", i);
      exit(1);
    }
    if (!FIFO_PRESENT(sys_sts_get_adc_data_fifo_status(&hw.sys_sts, i, verbose))) {
      fprintf(stderr, "Error: ADC data FIFO for board %u is not present. Channel count may be too high for hardware configuration.\n", i);
      exit(1);
    }
  }

  return hw;
}

// Print full hardware status to stdout
void hw_status_summary(hw_t *hw) {
  if (hw == NULL) {
    fprintf(stderr, "Error: hw pointer is NULL in hw_status_summary.\n");
    return;
  }
  // Print state
  printf("  Hardware status        : ");
  print_hw_status(sys_sts_get_hw_status(&hw->sys_sts, hw->verbose), hw->verbose);
  printf("  Trigger count          : %u\n", hw_get_trigger_count(hw));
  // Print FIFO buffer count for each board
  uint32_t board_count = (hw->channel_count - 1) / 8 + 1;
  for (uint32_t board = 0; board < board_count; board++) {
    printf("  DAC %u cmd FIFO count   : %u\n", board, FIFO_STS_WORD_COUNT(sys_sts_get_dac_cmd_fifo_status(&hw->sys_sts, board, hw->verbose)));
    printf("  DAC %u data FIFO count  : %u\n", board, FIFO_STS_WORD_COUNT(sys_sts_get_dac_data_fifo_status(&hw->sys_sts, board, hw->verbose)));
  }
  for (uint32_t board = 0; board < board_count; board++) {
    printf("  ADC %u cmd FIFO count   : %u\n", board, FIFO_STS_WORD_COUNT(sys_sts_get_adc_cmd_fifo_status(&hw->sys_sts, board, hw->verbose)));
    printf("  ADC %u data FIFO count  : %u\n", board, FIFO_STS_WORD_COUNT(sys_sts_get_adc_data_fifo_status(&hw->sys_sts, board, hw->verbose)));
  }
  printf("  Trigger cmd FIFO count : %u\n", FIFO_STS_WORD_COUNT(sys_sts_get_trig_cmd_fifo_status(&hw->sys_sts, hw->verbose)));
  printf("  Trigger data FIFO count: %u\n", FIFO_STS_WORD_COUNT(sys_sts_get_trig_data_fifo_status(&hw->sys_sts, hw->verbose)));
  return;
}

// Configure clock to 10 MHz. Returns 0 on success, non-zero on failure
// Returns 0 on success, non-zero on failure
int hw_set_clk(hw_t *hw) {
  if (hw == NULL) {
    return -1;
  }
  if (hw->verbose) {
    printf("Configuring SPI clock to 10 MHz...\n");
  }
  if (clk_ctrl_set_target_freq(&hw->clk_ctrl, &hw->sys_sts, 10e6, hw->verbose) != 0) {
    fprintf(stderr, "Error: failed to set SPI clock frequency.\n");
    return -1;
  }
  // Sleep to allow hardware to stabilize after clock change
  HW_SLEEP;
  // Verify that clock frequency is within 100 kHz of target
  uint32_t clk_freq = sys_sts_get_clk_freq_hz(&hw->sys_sts, hw->verbose);
  if (hw->verbose) {
    printf("SPI clock frequency set to %u Hz\n", clk_freq);
  }
  if (clk_freq < 9.9e6 || clk_freq > 10.1e6) {
    fprintf(stderr, "Error: SPI clock frequency %u Hz is out of expected range (9.9 MHz - 10.1 MHz).\n", clk_freq);
    return -1;
  }
  return 0;
}
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

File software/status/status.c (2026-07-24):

#include <stdio.h>
#include <stdlib.h>
#include <stdint.h>
#include <stdbool.h>
#include <inttypes.h>

#include <string.h>

#include "sys_sts.h"

static void print_usage(const char *prog) {
  printf(
      "Usage: %s [-h|--help]\n"
      "\n"
      "Read-only diagnostic tool for the Rev D shim amplifier. Reads the FPGA\n"
      "system status register (mapped at 0x40100000) and prints a human-readable\n"
      "snapshot of the hardware state. It only observes and reports, and never\n"
      "drives or reconfigures the hardware.\n"
      "\n"
      "Takes no arguments. Run it on the target to dump the current status.\n"
      "\n"
      "Reports:\n"
      "  - Hardware status: decoded state, status code, and associated board.\n"
      "  - Trigger count: number of hardware triggers seen.\n"
      "  - Clock frequencies: SPI clock and SPI source clock, in Hz.\n"
      "  - Timing debug register: clock-locked/SPI-off flags, DAC/ADC ~CS high\n"
      "    times, and SPI clock snoop reconfiguration state machine state.\n"
      "  - Minimum delay times: DAC and ADC \"delay too short\" thresholds.\n"
      "  - Per-board FIFO status (boards 0-7): DAC/ADC command/data FIFO status,\n"
      "    last received command word, and command count since reset.\n"
      "  - Trigger FIFOs: command and data FIFO status.\n"
      "\n"
      "Options:\n"
      "  -h, --help    Show this help message and exit.\n",
      prog);
}

int main(int argc, char *argv[]) {
  for (int i = 1; i < argc; i++) {
    if (strcmp(argv[i], "-h") == 0 || strcmp(argv[i], "--help") == 0) {
      print_usage(argv[0]);
      return EXIT_SUCCESS;
    }
    fprintf(stderr, "Unknown argument: %s\n", argv[i]);
    print_usage(argv[0]);
    return EXIT_FAILURE;
  }

  struct sys_sts_t sys_sts = create_sys_sts(false);

  uint32_t hw_status = sys_sts_get_hw_status(&sys_sts, false);

  printf("Hardware status:\n");
  print_hw_status(hw_status, true);
  printf("\n");

  printf("Trigger count          : %u\n", sys_sts_get_trig_count(&sys_sts, false));
  print_clk_freq(sys_sts_get_clk_freq_hz(&sys_sts, false), false);
  printf("SPI source ");
  print_clk_freq(sys_sts_get_source_clk_freq_hz(&sys_sts, false), false);
  printf("\n");

  print_debug_register(&sys_sts);
  printf("\n");

  printf("DAC min delay time     : %u cycles\n", sys_sts_get_dac_min_delay_time(&sys_sts, false));
  printf("ADC min delay time     : %u cycles\n", sys_sts_get_adc_min_delay_time(&sys_sts, false));
  printf("\n");

  for (uint8_t board = 0; board < 8; board++) {
    char name[64];
    snprintf(name, sizeof(name), "DAC %u cmd FIFO", board);
    uint32_t dac_cmd_status = sys_sts_get_dac_cmd_fifo_status(&sys_sts, board, false);
    print_fifo_status(dac_cmd_status, name);
    snprintf(name, sizeof(name), "DAC %u data FIFO", board);
    uint32_t dac_data_status = sys_sts_get_dac_data_fifo_status(&sys_sts, board, false);
    print_fifo_status(dac_data_status, name);

    if (FIFO_PRESENT(dac_cmd_status)) {
      printf("  Last received DAC command for board %u: 0x%08" PRIx32 "\n",
             board,
             sys_sts_get_last_received_dac_cmd(&sys_sts, board, false));
    }
    printf("  DAC commands since reset for board %u: %u\n",
           board,
           sys_sts_get_dac_cmds_since_reset(&sys_sts, board, false));
    printf("\n");
  }

  for (uint8_t board = 0; board < 8; board++) {
    char name[64];
    snprintf(name, sizeof(name), "ADC %u cmd FIFO", board);
    uint32_t adc_cmd_status = sys_sts_get_adc_cmd_fifo_status(&sys_sts, board, false);
    print_fifo_status(adc_cmd_status, name);
    snprintf(name, sizeof(name), "ADC %u data FIFO", board);
    uint32_t adc_data_status = sys_sts_get_adc_data_fifo_status(&sys_sts, board, false);
    print_fifo_status(adc_data_status, name);

    if (FIFO_PRESENT(adc_cmd_status)) {
      printf("  Last received ADC command for board %u: 0x%08" PRIx32 "\n",
             board,
             sys_sts_get_last_received_adc_cmd(&sys_sts, board, false));
    }
    printf("  ADC commands since reset for board %u: %u\n",
           board,
           sys_sts_get_adc_cmds_since_reset(&sys_sts, board, false));
    printf("\n");
  }

  print_fifo_status(sys_sts_get_trig_cmd_fifo_status(&sys_sts, false), "Trigger cmd FIFO");
  print_fifo_status(sys_sts_get_trig_data_fifo_status(&sys_sts, false), "Trigger data FIFO");
  printf("\n");

  return EXIT_SUCCESS;
}

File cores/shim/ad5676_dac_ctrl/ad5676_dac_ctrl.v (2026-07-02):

`timescale 1 ns / 1 ps

module ad5676_dac_ctrl #(
  parameter integer ABS_CAL_MAX = 4096,
  parameter integer ABS_DAC_MAX = 32767
)(
  input  wire        clk,
  input  wire        resetn,
  input  wire        halt,

  input  wire        boot_test_skip, // Skip the boot test sequence
  input  wire        debug,          // Debug mode flag
  input  wire        do_pre_delay,   // Whether to do the pre-delay before DAC writes that require a delay
  input  wire [ 4:0] n_cs_high_time, // n_cs high time in clock cycles (max 31)
  input  wire [24:0] min_delay_time, // Minimum delay time for DAC update commands in clock cycles

  input  wire signed [15:0] cal_init_val, // Default calibration value for all channels on reset (in 2's complement)

  output reg         setup_done,

  output wire        cmd_buf_rd_en,
  input  wire [31:0] cmd_buf_word,
  input  wire        cmd_buf_empty,
  input  wire        blocked,

  output reg         data_buf_wr_en,
  output reg  [31:0] data_word,
  input  wire        data_buf_full,

  input  wire        trigger,
  input  wire        ldac_shared,
  output wire        waiting_for_trig,

  output reg         boot_fail,
  output reg         cmd_buf_underflow,
  output reg         data_buf_overflow,
  output reg         unexp_trig,
  output reg         ldac_misalign,
  output reg         delay_too_short,
  output reg         bad_cmd,
  output reg         cal_oob,
  output reg         dac_val_oob,
  output reg [31:0]  last_received_cmd,
  output reg [31:0]  cmds_since_reset,

  output reg [119:0] abs_dac_val_concat,

  output reg         n_cs,
  output wire        mosi,
  input  wire        miso_sck,
  input  wire        miso_resetn,
  input  wire        miso,
  output reg         ldac
);

  // Validate parameters
  initial begin
    if (ABS_CAL_MAX < 0 || ABS_CAL_MAX > 32767)
      $error("Invalid value for ABS_CAL_MAX parameter: %d. Must be between 0 and 32767.", ABS_CAL_MAX);
    if (ABS_DAC_MAX < 0 || ABS_DAC_MAX > 32767)
      $error("Invalid value for ABS_DAC_MAX parameter: %d. Must be between 0 and 32767.", ABS_DAC_MAX);
  end

  localparam signed [15:0] ABS_CAL_MAX_SIGNED = ABS_CAL_MAX[15:0];
  localparam signed [16:0] ABS_DAC_MAX_SIGNED = ABS_DAC_MAX[16:0];

  ///////////////////////////////////////////////////////////////////////////////
  // SPI Timing Parameters
  ///////////////////////////////////////////////////////////////////////////////

  // SPI bit position for MISO read start
  localparam [4:0] SPI_BIT_MISO_START = 5'd18;

  ///////////////////////////////////////////////////////////////////////////////
  // SPI Command Bit Definitions
  ///////////////////////////////////////////////////////////////////////////////

  localparam DAC_TEST_CH   = 3'd5;      // DAC channel for testing
  localparam DAC_TEST_VAL  = 16'h800A;  // Test value for DAC channel
  localparam DAC_MIDRANGE  = 16'h8000;  // Midrange value

  localparam SPI_CMD_LDAC_WRITE = 4'b0001; // Register write command (wait for LDAC)
  localparam SPI_CMD_IMMED_WRITE = 4'b0011; // Register write command (immediate)
  localparam SPI_CMD_REG_READ  = 4'b1001; // Register read command


  ///////////////////////////////////////////////////////////////////////////////
  // State Machine and Command Definitions
  ///////////////////////////////////////////////////////////////////////////////

  // FSM states
  localparam S_RESET     = 4'd0;
  localparam S_INIT      = 4'd1;
  localparam S_TEST_WR   = 4'd2;
  localparam S_REQ_RD    = 4'd3;
  localparam S_TEST_RD   = 4'd4;
  localparam S_SET_MID   = 4'd5;
  localparam S_IDLE      = 4'd6;
  localparam S_DELAY     = 4'd7;
  localparam S_TRIG_WAIT = 4'd8;
  localparam S_DAC_WR    = 4'd9;
  localparam S_DAC_WR_CH = 4'd10;
  localparam S_PRE_DELAY = 4'd11;
  localparam S_ERROR     = 4'd15;

  // Command types
  localparam CMD_NO_OP     = 3'd0;
  localparam CMD_SET_CAL   = 3'd1;
  localparam CMD_DAC_WR    = 3'd2;
  localparam CMD_DAC_WR_CH = 3'd3;
  localparam CMD_GET_CAL   = 3'd4;
  localparam CMD_ZERO      = 3'd5;
  localparam CMD_CANCEL    = 3'd7;
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

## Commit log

2025-02-01 First attempt at rev_d_shim pinout files
    [pinout.csv]
2025-02-05 More XDC tweaks
    [pinout.csv]
2025-02-06 Fixed some ports.xdc mistakes
    [ports.xdc]
2025-02-07 Parity mistake on ADC_MISO_4
    [ports.xdc]
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2025-02-10 Fixed pinout issue from pinout CSV
    [pinout.csv]
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2025-02-19 Rev D shim SPI clock core locked. AXI dynamic reconfig not working. Makefile updated to properly identify dependencies and rebuild accordingly. Also added clean_project target that removes the tmp fi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
2025-03-28 Added synchronization for SPI clock domain to rev d shim and changed the polarity of shutdown_force in rev d shim and shim controller v0
2025-04-01 Added syncrhonization for status signals out of SPI clock domain. Updated axi cfg registers to have more robust sanitization and errors
2025-04-08 Refactored the user_cores directory to be named custom_cores. I like this naming better. Uploaded the source files for the DMA module. Played around with the start of the PetaLinux build process to a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
2025-04-09 Starting an AXI DMA flow control core. Updated the shim cfg core to add cfg values for this. Updated the UART1 baud for rev_d_shim project to the maximum rate. Added the AXI_ACP port to the rev_d_shi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
2025-04-29 Completed block design for example DMA project. Refactored the project.tcl addr procedure to take a target address space interface pin, which was necessary for the DMA project.
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2025-05-24 Removed threshold integrator from ADC channels. Added utilization check script. Utilization passes currently
2025-05-28 Added AXI interface to DAC/ADC FIFOs. Moved DAC/ADC FIFOs into their own module
2025-05-28 Started adding a variable board count to make testing and compatability a little easier
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2025-05-28 Removed unnecessary loop_pins TCL procedure, just used normal loops with the wire procedure
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2025-06-03 Fixed auto-connect AXI TCL proc (used in shim_controller_v0). Fixed dac_val_oob not latching high. Added waiting_for_trigger signal so the future trigger_core can synchronize DAC and ADC channels
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2025-06-17 Working build with updated trigger time data buffer and adc core incorporated
2025-06-17 Repo cleanup -- removed some unnecessary custom cores and removed the half-baked DMA examples
2025-06-18 Changed trig_en to 'block_buffers', blocking all command and data buffers by overriding the empty/full flags on the SPI side until unblocked
2025-06-18 Added tracking of ADC and DAC boot check failure (logic not implemented yet). Reordered boot process for HW manager to run SPI boot process before powering on the amplifier board
2025-07-07 Successful build with ADC and DAC cores refactored for proper timing handling
2025-07-08 First attempt at MISO interaction with DAC SPI core. Delay calculated to be about 10ns, which is half a clock cycle at 50 MHz
2025-07-14 Some work on block design for interrupts example. Much more to be done
2025-07-29 File beautified (#11)
    * READMEs on Communication Protocols
    * TCP/IP streaming C code
    * READMEs on Communication Protocols
    * README on File Transfer over the Serial Interface (UART)
    * files renamed in the master
    * Trying to sync renaming in the master.
    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
2025-07-29 Added a quick script to copy over device tree source include files. Refactored kernel module include files to be stored in the cfg petalinux per-version, and removed the version aspect from the top k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
2025-07-29 Detailed info being added for PPP over UART (work in progress) (#12)
    * Beautified the text.
    * Adding detailed info but it is still work in progress!
    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
2025-08-01 Added interrupt device tree to Rev D shim project. Fixed some small block design bugs for a full compilation of Rev D shim
    [kernel_config.cfg]
2025-08-04 Refactored the monolithic rev-c-one-to-one into a good structure for future. Current plan is to create incremental software steps to bench test the system
2025-08-07 edited the two READMEs (#13)
    * a complete rewrite of TCP README
    * Fixed a typo.
    ---------
    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
2025-08-08 Switched SPI clock poweroff to much simpler approach, just gating the actual output clock. Hopefully this fixes bootup issues
2025-08-08 Made it past the spi reset confirmation. Stuck on spi start (boot sequence). Exploring further
2025-08-08 Slight refactor of status codes and AXI register order. Attempt to add boot_test_skip for the DAC/ADC cores. Still stuck on SPI_START_TIMEOUT
2025-08-12 Tweaked reset cores, SPI clock negation, and SPI clock default rate to get the bench test loading. Adding a debug option to the block design to output MISO data to the buffers. Needs a refactor of th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
2025-08-12 First attempt refactoring the buffer system to include DAC data buffers and make the data/command buffer access just one pointer. Added all this to allow for the boot test debug for DAC and ADC cores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
2025-08-13 Successfully built the debug test. Debug info isn't coming through yet, probably to do with the block_bufs set from the hardware manager. ADC is also setting CS low for a few seconds too long, not su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
2025-08-15 Working boot-up check on hardware. Fixed small mistakes and added debug to the ADC and DAC control cores. Significantly updated the software interface for controlling.
2025-08-18 Renamed testing software to shim-test. Starting adding DAC and ADC control commands to the source C code files (not yet to the command processing loop)
2025-08-18 Added trigger commands to C code. Tweaked exit approach for adc and dac c code. No CLI code yet
2025-08-19 Added some command handler C code for ADC, DAC, and Trigger management. Fixed the trigger core to properly capture the entire 64-bit word before writing it out, instead of possibly causing errors by 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
2025-08-19 Updated ADC and DAC control C code to handle trigger count values in addition to delays
2025-08-19 Added handler commands to the C code for trigger and basic dac/adc control (only no-op and cancel for now).
2025-08-19 Tweaked commands print responses and added a hard reset command
2025-08-22 DAC timing is working, need to add ADC SPI mode change functionality
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2025-08-26 Added new errors for LDAC misalignment, DAC/ADC delay too short checks, and a command to write DAC commands
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2025-08-28 Added an extra bit to the ADC command (README out of date) and tweaked ergonomics of DAC and ADC command code
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2025-08-29 Milestone: ADC successfully and accurately reads back DAC square pulse on one channel
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2025-09-02 Started on DAC/ADC high time calculation from SPI clock frequency. Currently SPI clock frequency is set during the build (at least for these calculation cores), but eventually I'll add an interceptor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
2025-09-02 Reordered DAC/ADC commands again to make room for DAC_WR_CH and ADC_RD_CH commands to simply and immediately read/write a single channel without updating them. Implementation has NOT been done yet, w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
2025-09-03 Added DAC/ADC WR/RD single channel commands to shim-test. Started a waveform generation file
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2025-09-11 Tried to fix the adc read commands in the C code to handle the signed/offset coversion properly
2025-09-11 Updated AXI fifo bridge to have read and write reset separate so they can be handled by the different reset sources of the buffer reset control. Fixed some silly C mistakes missing print statements
2025-09-15 Updated the ADC data streaming to write ASCII by default, while keeping binary write as an option for speed. Added Python conversion script
2025-09-17 Attempt to fix the ADC read timing issues. Simplified the calculation cores and hopefully removed some multiplication overflow issues
2025-09-22 Added the ability to get current calibration from the DAC channel. Also finally found a very bizarre bug with the ADC data buffer -- putting the word inside a macro and doing a bitwise operation on i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
2025-09-23 Fixed issues with the offset change not being properly implemented. Added channel calibration command to work over everything
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2025-10-07 Added trigger counting, fixes to flag management in software, ADC bias tests, and some quality of life changes. Unfortunately seem to have some kind of regression in the waveform test and fieldmappin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
    [shim-test.c]
2025-10-09 Added DXF-based outlines of the MGH bullfinch building as a fancy test waveform
    [line_1.dxf, line_2.dxf, line_3.dxf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]
2025-10-10 Tested ADC responses on the bench
    [line_1.dxf, line_2.dxf, line_3.dxf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]
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2025-10-16 DAC zero and ADC repeat rework implemented
2025-10-17 Big day with lots of fixes. Cleaned up some metastability of the trigger pulses coming in, and rewrote a good bit of C code to clear some bugs
    [pinout.csv]
2025-10-17 Fixed expected ADC sample count for rev c compat
2025-10-17 Fixed ADC 0-delay wait instead of 0-trigger wait at the end of the rev c compat zero line
2025-11-24 Added some new python files and stopped tracking waveform, readout, log, and csv files. Removed tracking for those that were already tracked
    [pinout.csv]
2025-12-01 Fixed calibration in software, updated the convert waveform python script
    [convert_waveform.py]
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2025-12-24 Dynamic range is now exactly 5.0A. Updated fieldmap to include 0 stage for field adjust. Fixed DAC out of bounds check and ADC RD CH command for the recent switch to signed integers
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2026-03-12 Add 'custom_cores/rev_d_shim/' from commit 'bbeeb5c64652d40e9d3edb3520e3d1d169bd9da3'
    git-subtree-dir: custom_cores/rev_d_shim
    git-subtree-mainline: bf0d424c5bf783f5af8a200edc78fbc2f592523c
    git-subtree-split: bbeeb5c64652d40e9d3edb3520e3d1d169bd9da3
    [kernel_config.cfg]
2026-03-12 Added fifo_async submodule symlink to dac and adc ctrl cores, and fixed all dac ctrl verilator warnings (but not the tests yet)
    [ad5676_dac_ctrl.v]
2026-03-13 Cleaned up DAC and ADC tests. Fixed a bug with dac_wr_ch, unsure if it could cause the issue I was seeing with dac thresholding -- builds, though. Added software commands to test the dac changes on t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
    [ad5676_dac_ctrl.v, ad5676_dac_timing_calc.v, ads816x_adc_ctrl.v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]
2026-03-18 Attempted to fix channel_cal issue (DAC core was pulsing LDAC on immediate single-channel writes, which likely was causing issues with the chip) and threshold_integrator problems (cleaned up bitwidth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
    [ad5676_dac_ctrl.v, threshold_integrator.v]
2026-05-19 Removed the ability to flip MISO/MOSI clock polarity to simplify
    [hw_manager.v, ports.xdc]
2026-05-21 Moved secondary 5 MHz clock to be sourced from PS, saving a clock management tile and improving the clock resource routing. Still failing hold timing on four cores, unsure how to improve on that.
    [ad5676_dac_ctrl.v, ports.xdc]
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2026-05-22 EXPERIMENTAL: Hopefully changed DAC behavior to allow sending DAC_WR commands with an empty buffer without immediate underflow errors
    [ad5676_dac_ctrl.v]
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2026-05-28 Fixed a potential glitch with a DAC word being read as a cancel command
    [ad5676_dac_ctrl.v]
2026-05-28 Created looping version of async FIFO for future use of DAC commands. Added last recieved command and command count since reset for DAC and ADC cores. Neither feature is implemented yet in the block 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
    [line_1.dxf, line_2.dxf, line_3.dxf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]
2026-05-29 Added DAC/ADC last recieved commands and commands since last reset to help sequence debugging
    [ad5676_dac_ctrl.v, ads816x_adc_ctrl.v]
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2026-06-02 Fixed some mistakes and bugs, clock gating was being bypassed. Waveforms are working well, so are DAC/ADC last commands. SPI clock configuration snoop core is sticking in reconfiguration, added info 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
    [ads816x_adc_ctrl.v, axi_clock_timing_snoop.v, hw_manager.v]
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2026-06-16 Tweaked cancel behavior in DAC core to prevent DAC activation after commands
    [ad5676_dac_ctrl.v, ads816x_adc_ctrl.v]
2026-06-18 Fixed bad reset buffer bit assignments
    [hardware.c]
2026-06-23 First pass making the basic steps work. Fixed an issue with erroneous commands coming out of CMD buffers when resetting them. Made the static-shims compile and run otherwise
    [ad5676_dac_ctrl.v, ads816x_adc_ctrl.v, commands.c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]
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2026-06-30 First attempt at file loading for static-shims. Updated DAC/ADC to no longer give unexpected trigger errors if in IDLE state (no commands running) to allow unused boards to just sit. Started outline 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
    [ad5676_dac_ctrl.v, ads816x_adc_ctrl.v, commands.c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]
2026-06-30 Clean build of static-shims! Fixed trigger core not properly handling infinite triggers and added quality of life improvements
    [commands.c, hardware.c]
2026-07-02 Cleaned up the help for static-shims. Improved the threading in shim-tests to hopefully shut themselves off when detecting a hardware error. Cleaned up the blocking for DAC/ADC/Trigger cores too stop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
    [ad5676_dac_ctrl.v, ads816x_adc_ctrl.v, commands.c]
2026-07-09 Added emergency reset-shims binary and attempt at Array (A) command in static-shims
    [commands.c]
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2026-07-24 Fixed some merge issues
    [waveform.c]
